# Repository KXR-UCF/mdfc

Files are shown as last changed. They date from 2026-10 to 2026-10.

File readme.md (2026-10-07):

## **LTI Modular DAQ & Flight Computer**


This is a teensy 4.1 based analog data acquisition system and flight computer.

It consists of 5 PCBs:

**Heisenberg (Mainboard)**

The Heisenberg board carries the Teensy 4.1 and all the modules, mounts to the chassis, and has the servo/aux connector. It provides the same pinout to each of the two modules so they are interchangeable.



**Fring/Schrader (Flight/Ground Power Modules, these will most likely be two different PCBs)**

These boards convert input voltage, either from battery during flight use or power over ethernet for ground use, into the necessary voltages for the rest of the system. They also handle the ethernet input to the Teensy 4.1, and allow the Teensy 4.1 to independently enable/disable each voltage output.



**Goodman (ADC Module)**
This board carries the HiLetgo ADS1256 board, along with analog circuitry and a sensor connector, for use with analog sensors such as Pressure Transducers, Thermocouples, and Load Cells. A future development will be to create a fully SRAD ADC module instead of relying on the COTS ADS1256 board.

**Pinkman (Flight Sensor/Telemetry Module)**
This board contains flight sensors (IMU and barometric), a GPS receiver, and a 433 MHz LoRa radio for telemetry in flight.



The Heisenberg board has 2 module slots and 1 power module slot, and its two primary configurations are as follows:

* DAQ/Ground use: 
	Module A: Goodman
	Module B: Goodman
	Power Module: Schrader
PoE powered, 16 channel analog input, no flight sensor/telemetry, no servo output.
* Flight use:
	Module A: Goodman
	Module B: Pinkman
	Power Module: Fring
Battery powered, 8 channel analog input, flight sensors/telemetry, servo output.

**The primary goals of this project are:**

* Emulate the EE design, collaboration, integration, and test processes used in the aerospace industry to provide a valuable learning experience for members
* Increase the sampling speed of the DAQ system
* Increase the expandability of the DAQ system
* Move ADCs closer to sensors to decrease analog wire length for less noise
* Improve power filtering for ADCs and load cells
* Record fast analog data in flight
* Transmit flight data to ground via telemetry at the highest speed possible
* Create a platform that can be expanded and upgraded by future students

## Copyright

Copyright © 2026 Knights Experimental Rocketry (KXR). All Rights Reserved.

No permission is granted to reproduce, modify, distribute, manufacture from,
or commercially use the contents of this repository without written
authorization from KXR.

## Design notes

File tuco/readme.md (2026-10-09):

## TUCO:
Tuco is a large, single sided (except the teensy), 2 layer (ideally) mainboard with test connectors for all the signals coming from the teensy. It acts as an exploded version of Heisenberg, so the software can be bench tested, the power supplies can be stress tested and analyzed, and signal issues can be troubleshooted.

It is designed to fit onto a standard breadboard with the 40 pin header for the module connectors, and the 10 pin header using an extender cable for the servo connector. It has high current screw terminals on the power rails for stress testing the power module, or externally powering the board for testing. It also has larger free space for indicator LEDs or test points to be added at a later date.





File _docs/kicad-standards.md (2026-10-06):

## This is copied from sharepoint, the sharepoint version is the official version

**LTI MDFC Github/Kicad Standards**
https://github.com/KXR-UCF/mdfc 
All MDFC boards will be made in KiCad 10.

# File Naming Convention
Each PCB project and folder should use the existing board name:
heisenberg/
goodman/
pinkman/
fring/
schrader/
Project files should use the same lowercase board name.
For hierarchical schematic sheets, use short descriptive lowercase names separated by hyphens.
Examples:
power
sensors
servo-output
pressure-inputs
radio
gps
power-regulation
Avoid generic names such as sheet1 or schematic2.

# Libraries
Common library: _libraries/  Use for symbols/footprints/3d models shared between multiple MDFC boards. 
Local library: in each project folder such as /heisenberg/heisenberg.kicad_sym Used for all other parts
All library paths must be relative to the project/repository, not specific to your computer. For example (individual libraries):
Symbols:
${KIPRJMOD}/goodman.kicad_sym
Footprints:
${KIPRJMOD}/goodman.pretty
3D models:
${KIPRJMOD}/goodman.3dshapes/part.step
(Shared libraries):
Symbols:
${KIPRJMOD}/../_libraries/mdfc-common.kicad_sym
Footprints:
${KIPRJMOD}/../_libraries/mdfc-common.pretty
3D models:
${KIPRJMOD}/../_libraries/mdfc-common.3dshapes/part.step

# Board Interfaces
The provided templates contain the required board outline, mounting holes, and connectors, do not change any of these without coordinating with the team or your board won’t fit onto the others.

# GITHUB WORKFLOW
Everyone will work directly on main.
1.	Open GitHub Desktop and Fetch/Pull the latest version of main before starting work.
2.	Work only inside your assigned PCB folder unless you are intentionally modifying a shared file.
3.	Make your changes in KiCad and save the project normally.
4.	Before committing, check the Changes tab in GitHub Desktop and make sure only files you intended to modify are being changed.
5.	Commit regularly with a short message describing the actual change.
Examples:
[GOODMAN] Add ADS1256 input stage
[PINKMAN] Add GPS circuitry
[FRING] Route 5V regulator
[HEISENBERG] Add servo output connectors
Avoid commit messages such as:
Update, changes, stuff, final, fixed etc. 
6.	Before pushing, Fetch/Pull again in case someone else has pushed changes since you started.
7.	If there are no conflicts, Push to main.
8.	If Git reports a conflict in a KiCad schematic, PCB, symbol, footprint, or shared library file, do not blindly combine the files. Coordinate with whoever changed the conflicting file before proceeding.
9.	Changes to _libraries/ or any other shared files should be coordinated with the team before editing.

# GENERAL RULE
Pull before starting work, pull again before pushing, commit regularly, and coordinate any change that affects shared files or another MDFC board.

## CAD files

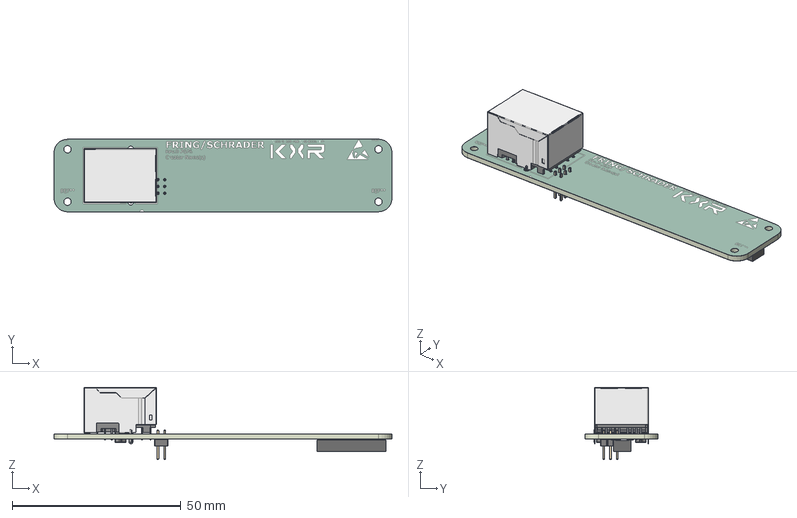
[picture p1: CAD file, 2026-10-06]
fring/fring.step
100.0 x 21.5 x 21.4 mm
Insulator
LED
Insulator_2
pins2
Shielding
HLE-108-02-DV_socket
C-132-12-08-L-DV
C-132-12-08-F-DV2
PinHeader_2x03_P200mm_Vertical
PowE0E3_silkscreen x 2
PowE0E3_soldermask x 2
PowE0E3_PCB

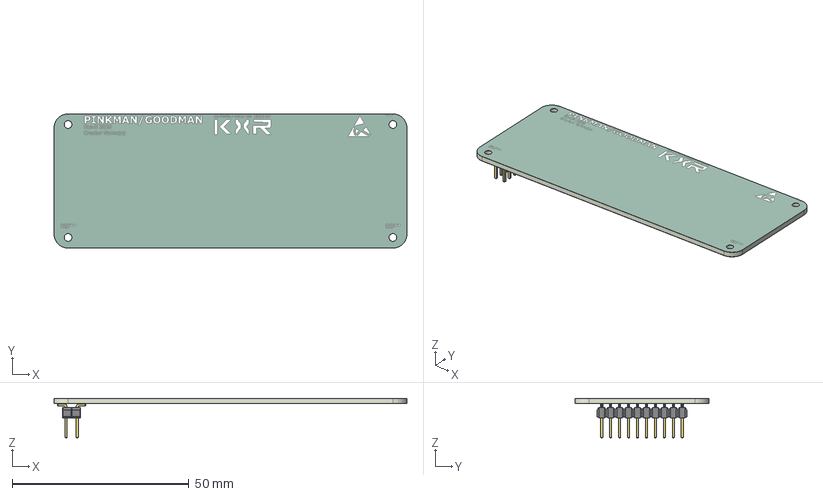
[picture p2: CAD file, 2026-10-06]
goodman/goodman.step
100.0 x 38.0 x 11.3 mm
Mod6616_silkscreen x 2
Mod6616_soldermask x 2
Mod6616_PCB

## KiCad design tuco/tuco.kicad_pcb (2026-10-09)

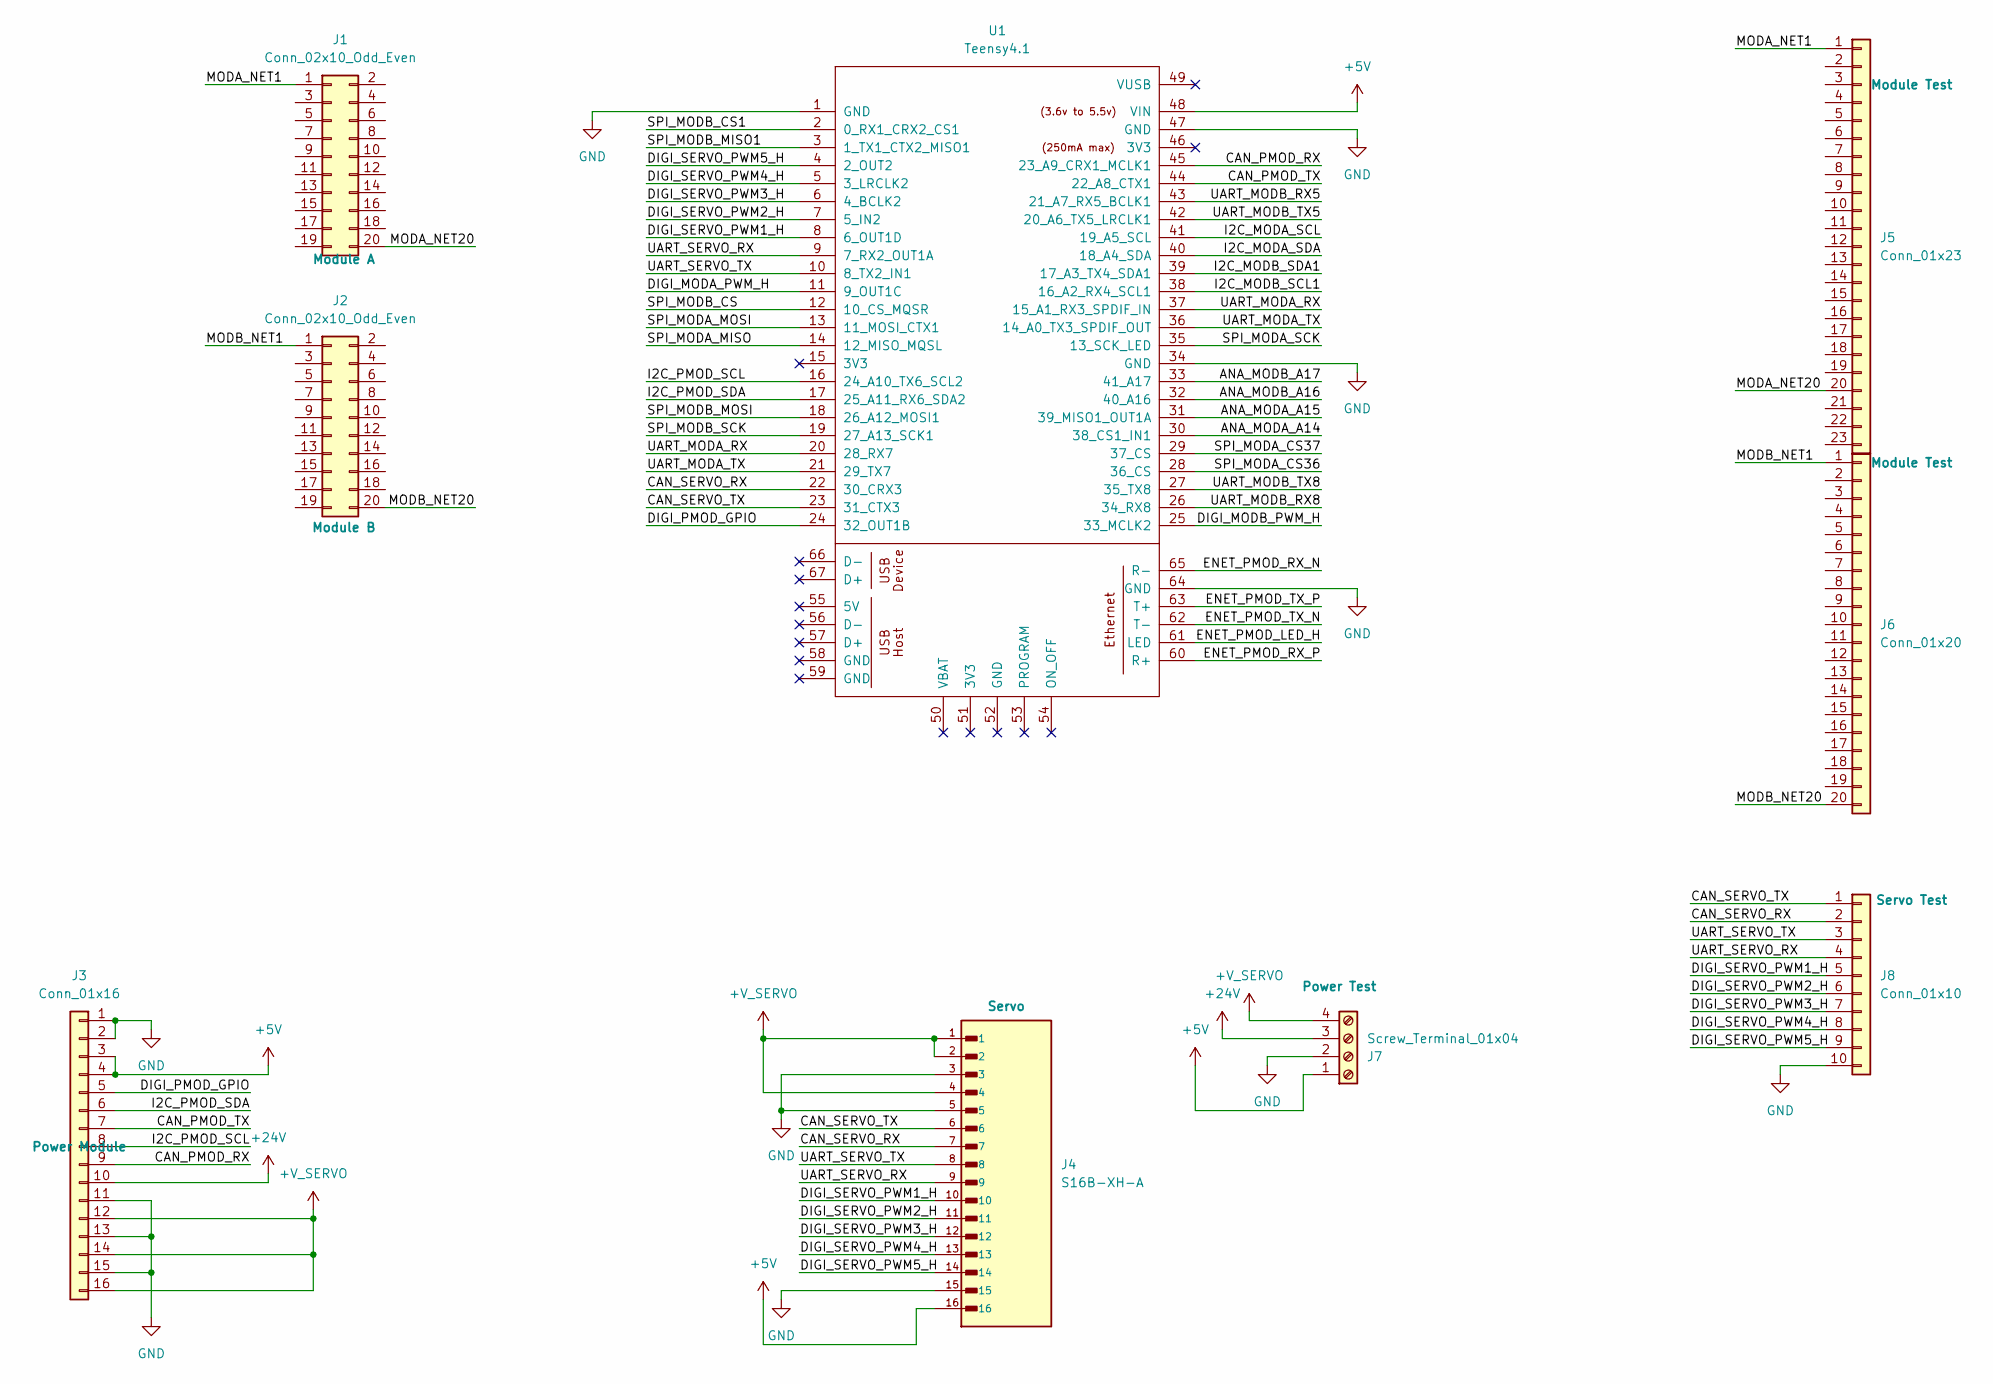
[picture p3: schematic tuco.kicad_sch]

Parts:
J1, J2: Conn_02x10_Odd_Even; PinSocket_2x10_P2.54mm_Vertical
J3: Conn_01x16; PinHeader_2x08_P2.54mm_Vertical
J4: S16B-XH-A; JST_XH_S16B-XH-A_1x16_P2.50mm_Horizontal
J5: Conn_01x23; PinHeader_1x23_P2.54mm_Vertical
J6: Conn_01x20; PinHeader_1x20_P2.54mm_Vertical
J7: Screw_Terminal_01x04; TerminalBlock_Phoenix_PT-1,5-4-5.0-H_1x04_P5.00mm_Horizontal
J8: Conn_01x10; PinHeader_1x10_P2.54mm_Vertical
U1: Teensy4.1; Teensy41

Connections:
+5V: J3.3, J3.4, J4.16, J7.1, U1.48 (VIN)
+24V: J3.10, J7.3
+V_SERVO: J3.12, J3.14, J3.16, J4.1, J4.2, J4.4, J7.4
/ANA_MODA_A14: U1.30 (38_CS1_IN1)
/ANA_MODA_A15: U1.31 (39_MISO1_OUT1A)
/ANA_MODB_A16: U1.32 (40_A16)
/ANA_MODB_A17: U1.33 (41_A17)
/CAN_PMOD_RX: J3.9, U1.45 (23_A9_CRX1_MCLK1)
/CAN_PMOD_TX: J3.7, U1.44 (22_A8_CTX1)
/CAN_SERVO_RX: J4.7, J8.2, U1.22 (30_CRX3)
/CAN_SERVO_TX: J4.6, J8.1, U1.23 (31_CTX3)
/DIGI_MODA_PWM_H: U1.11 (9_OUT1C)
/DIGI_MODB_PWM_H: U1.25 (33_MCLK2)
/DIGI_PMOD_GPIO: J3.5, U1.24 (32_OUT1B)
/DIGI_SERVO_PWM1_H: J4.10, J8.5, U1.8 (6_OUT1D)
/DIGI_SERVO_PWM2_H: J4.11, J8.6, U1.7 (5_IN2)
/DIGI_SERVO_PWM3_H: J4.12, J8.7, U1.6 (4_BCLK2)
/DIGI_SERVO_PWM4_H: J4.13, J8.8, U1.5 (3_LRCLK2)
/DIGI_SERVO_PWM5_H: J4.14, J8.9, U1.4 (2_OUT2)
/ENET_PMOD_LED_H: U1.61 (LED)
/ENET_PMOD_RX_N: U1.65 (R-)
/ENET_PMOD_RX_P: U1.60 (R+)
/ENET_PMOD_TX_N: U1.62 (T-)
/ENET_PMOD_TX_P: U1.63 (T+)
/I2C_MODA_SCL: U1.41 (19_A5_SCL)
/I2C_MODA_SDA: U1.40 (18_A4_SDA)
/I2C_MODB_SCL1: U1.38 (16_A2_RX4_SCL1)
/I2C_MODB_SDA1: U1.39 (17_A3_TX4_SDA1)
/I2C_PMOD_SCL: J3.8, U1.16 (24_A10_TX6_SCL2)
/I2C_PMOD_SDA: J3.6, U1.17 (25_A11_RX6_SDA2)
/MODA_NET1: J1.1, J5.1
/MODA_NET20: J1.20, J5.20
/MODB_NET1: J2.1, J6.1
/MODB_NET20: J2.20, J6.20
/SPI_MODA_CS36: U1.28 (36_CS)
/SPI_MODA_CS37: U1.29 (37_CS)
/SPI_MODA_MISO: U1.14 (12_MISO_MQSL)
/SPI_MODA_MOSI: U1.13 (11_MOSI_CTX1)
/SPI_MODA_SCK: U1.35 (13_SCK_LED)
/SPI_MODB_CS: U1.12 (10_CS_MQSR)
/SPI_MODB_CS1: U1.2 (0_RX1_CRX2_CS1)
/SPI_MODB_MISO1: U1.3 (1_TX1_CTX2_MISO1)
/SPI_MODB_MOSI: U1.18 (26_A12_MOSI1)
/SPI_MODB_SCK: U1.19 (27_A13_SCK1)
/UART_MODA_RX: U1.20 (28_RX7), U1.37 (15_A1_RX3_SPDIF_IN)
/UART_MODA_TX: U1.21 (29_TX7), U1.36 (14_A0_TX3_SPDIF_OUT)
/UART_MODB_RX5: U1.43 (21_A7_RX5_BCLK1)
/UART_MODB_RX8: U1.26 (34_RX8)
/UART_MODB_TX5: U1.42 (20_A6_TX5_LRCLK1)
/UART_MODB_TX8: U1.27 (35_TX8)
/UART_SERVO_RX: J4.9, J8.4, U1.9 (7_RX2_OUT1A)
/UART_SERVO_TX: J4.8, J8.3, U1.10 (8_TX2_IN1)
GND: J3.1, J3.2, J3.11, J3.13, J3.15, J4.3, J4.5, J4.15, J7.2, J8.10, U1.1 (GND), U1.34 (GND), U1.47 (GND), U1.64 (GND)

Board: 2 copper layers, 9 parts (1 on the bottom side), 24 nets, no tracks yet.

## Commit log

2026-10-01 Updated readme.md (Board photos, goals, formatting)
2026-10-06 Add initial board templates, kicad standards doc, adjust folder structure
    [Heisenberg.kicad_pcb, Heisenberg.kicad_sch, Module.kicad_pcb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]
2026-10-07 PROJECT START: Copied templates into project folders, renamed, fixed libraries/3d models.
    [Heisenberg_template.kicad_pcb, Heisenberg_template.kicad_sch, fring.kicad_pcb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]
2026-10-08 Created Tuco directory, started work on Tuco board
    Tuco is a larger, single sided, 2 layer version of Heisenberg for software development and test.
    [tuco.kicad_pcb, tuco.kicad_sch]
2026-10-09 Created Tuco board outline, heisenberg pin labels
    [heisenberg.kicad_pcb, heisenberg.kicad_sch, tuco.kicad_pcb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]
2026-10-09 TUCO: Added net labels, servo/power prelim pinouts
    [tuco.kicad_pcb, tuco.kicad_sch]
2026-10-12 Main board MOD A&B pins & routing
    V1 of the initial module A & B routing so other people can have a starting point for their pin layout
    dont mind the naming scheme i need to fix that
2026-10-13 Added goodman_pro for custom ADC Board.
2026-10-13 Added Schematics
2026-10-13 attempt number 2 at routing
    This time they are identical schematic layout for A & B and i used the 4 layers to route to potential via points b4 connection
2026-10-13 added symbols and ground
2026-10-16 working on schematic layout
2026-10-16 V2 pin layout main board
    Rerouted the wiring to the conectors on the main board in a better less cluttered way all that it needs is vias b4 connecting
2026-10-16 Addition to the V2 reroute update
    there was a unconnected pin and i untangled 1 route
2026-10-17 started labeling schematics
2026-10-19 Finished Schematic
    Used AI to help me with schematic design. Added a second page for Power & GNSS support.
2026-10-19 Uploaded all symbols, footprints, and 3D models.
2026-10-19 Simplified Schematic
2026-10-19 continuing labeling schematics
2026-10-19 Added some wire connections and filter logic.
2026-10-19 Cleaned up wiring.
2026-10-19 Removed hardware not needed for carrier board.
2026-10-20 Fixed ADC1256 wiring organization.
2026-10-23 Added Labels for Filters.
2026-10-26 updated power pins layouot
    apparently this was never pusheded
2026-11-03 finished correcting naming convention
    added a sample mosfet for the ethernet led
